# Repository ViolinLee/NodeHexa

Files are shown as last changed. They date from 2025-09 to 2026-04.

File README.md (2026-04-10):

# 🤖 NodeHexa - 六足机器人（支持四足构型）

[English README](README_EN.md)

<div align="center">

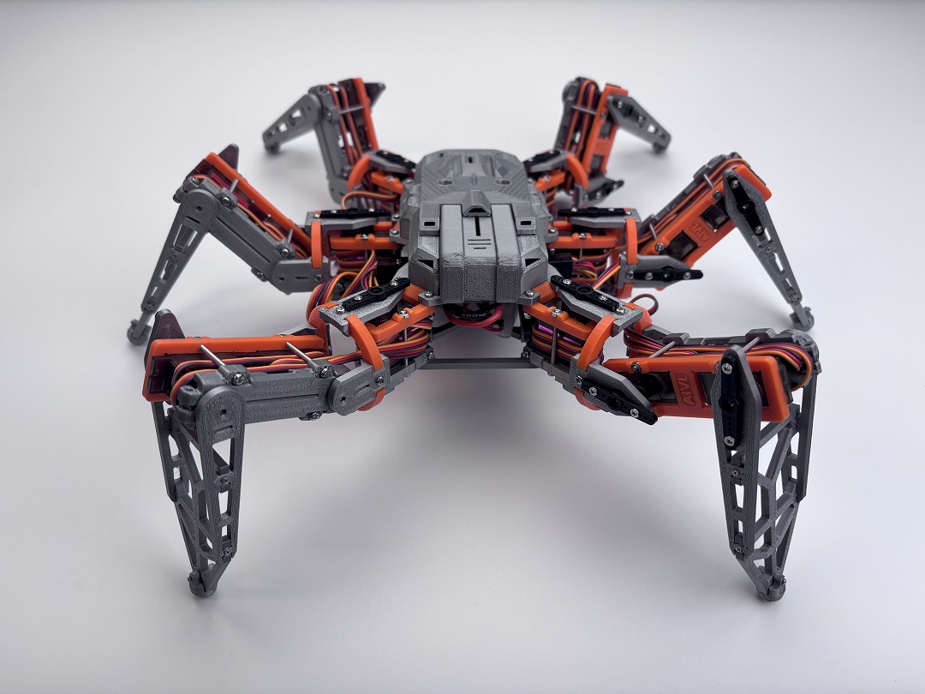
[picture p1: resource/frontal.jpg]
NodeHexa Logo


**一个基于 ESP32 的六足机器人项目，同时额外支持四足构型固件；支持 Web 控制、校准、表演动作与动作序列**






</div>

## 📖 项目简介

NodeHexa 是一个开源的六足机器人项目，基于 ESP32 微控制器开发。项目集成了运动学算法、Web 界面控制、实时校准与动作序列（运动规划）能力，面向机器人爱好者与研究用途。

## 🧩 支持的构型

当前代码仓库同时提供 **四足构型固件** 支持，便于共用一套 Web UI、校准与运动控制框架。

| 构型 | 定位 | 支持范围 | 文档/图片现状 |
| --- | --- | --- | --- |
| **六足（Hexapod / NodeHexa）** | 主线 | 结构/硬件/固件/界面/教程 | 本 README 的示意图主要为六足；软硬件设计完全开源 |
| **四足（Quadruped / NodeQuadMini）** | 额外支持 | 结构/原理图/固件/界面 | 本 README 已包含四足展示图；硬件侧提供原理图参考（PCB 未开源）；待更新教程 |

> 结构件与紧固件差异：见 `mechanism/README.md`（已按六足/四足分别列出）。

## ✨ 核心特性

### 🧩 双构型支持（六足为主，四足为额外支持）
- **统一抽象接口** - 六足/四足共用控制与 Web 框架
- **构型差异隔离** - 六足与四足分别实现，互不影响主线功能演进

### 🎮 多种控制方式
- **Web界面控制** - 通过浏览器实时控制机器人运动
- **串口通信** - 支持UART2串口指令控制（调试和外接上位机用）
- **WebSocket通信** - 低延迟的实时数据传输
- **语音拓展（可选）** - 支持接入“小智 AI 拓展板”，实现语音交互控制

### 🚀 丰富的运动模式
- **基础移动**: 前进、后退、左转、右转
- **侧向移动**: 左移、右移
- **姿态控制**: X/Y/Z轴旋转、扭转动作
- **特殊动作**: 攀爬、快速前进
- **表演模式**: 自由律动、节拍摇摆、登场秀
- **动作按钮模式切换**: 支持“持续”与“单次（单周期）”两种触发方式，普通动作与表演动作都会随设置切换执行方式
- **单腿演示模式（仅六足）**: 可单独选择一条腿进行前后/左右/抬升演示
- **四足多步态切换**: 支持 Trot / Walk / Gallop / Creep 步态模式切换
- **动作序列（运动规划）**: 将多段动作按“周期/步数/距离/角度”等约束编排成序列，一键执行（见 `/planner`）

### 🔧 精确校准系统
- **实时校准** - 通过Web界面进行舵机角度可视化校准
- **参数保存** - 校准数据自动保存到Flash存储

### 🔋 安全保护功能
- **电量显示** - 主控制页与运动规划页实时显示电压和估算电量百分比
- **电池监测** - 实时监控电池电压
- **低电压保护** - 自动LED警告和系统保护

## 🏗️ 技术架构

### 硬件平台
- **主控**: ESP32 (NodeMCU-32S)
- **舵机驱动**: PCA9685 PWM驱动板
- **通信**: WiFi + UART2串口
- **存储**: SPIFFS文件系统
- **语音拓展（可选）**: 小智 AI 拓展板

### 软件架构
```
firmware/
├── src/
│   ├── main.cpp          # 主程序入口
│   ├── robot.h            # 统一机器人抽象接口（六足/四足共用）
│   ├── hexapod.h/cpp      # 六足实现
│   ├── quad_robot.h/cpp   # 四足实现
│   ├── leg.h/cpp          # 单腿控制（六足/四足各自实现/复用）
│   ├── movement*.h/cpp    # 运动控制算法与配置表
│   ├── motion_controller* # 动作序列/运动规划执行
│   └── calibration.h/cpp  # 校准系统
├── include/              # 头文件
└── lib/                  # 第三方库
```

## 🎯 运动控制算法

### 运动学计算
- **正运动学**: 根据关节角度计算足端位置
- **逆运动学**: 根据目标位置计算关节角度
- **坐标变换**: 世界坐标系与局部坐标系转换

## 🖼️ 项目展示

### 六足（NodeHexa）结构与硬件设计

<table>
  <tr>
    <td align="center">
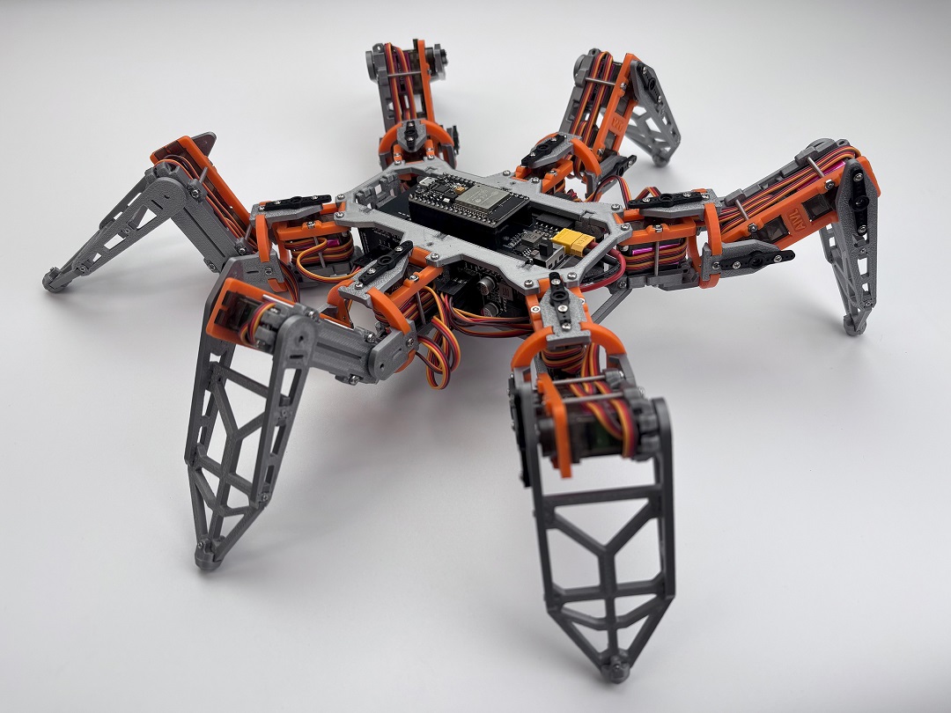
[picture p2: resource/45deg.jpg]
结构设计
      
      <br/>
      <em>六足结构</em>
    </td>
    <td align="center">
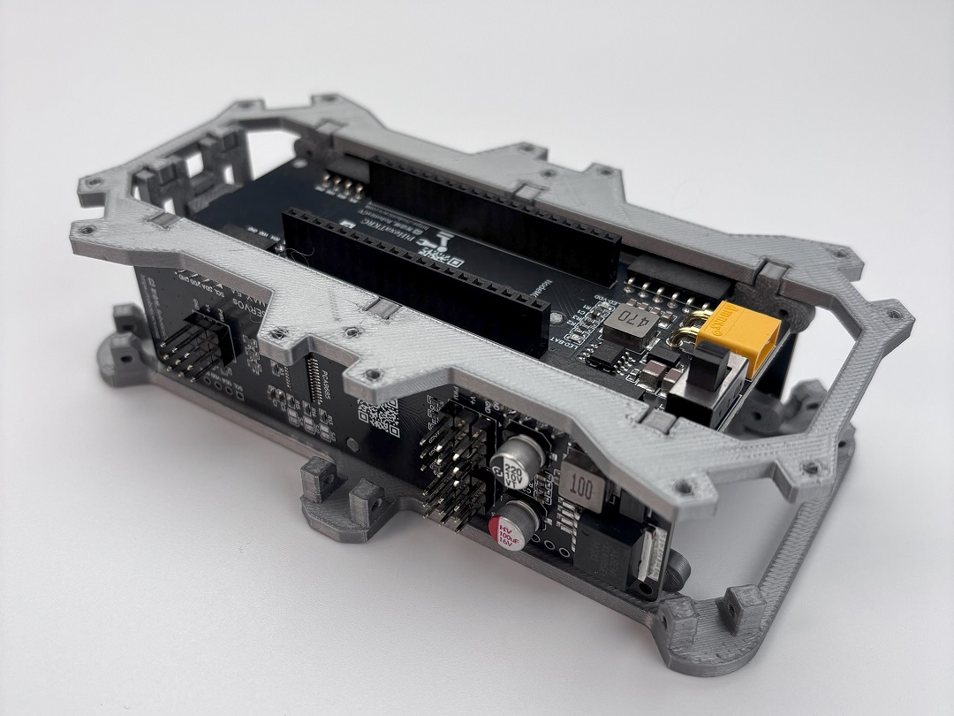
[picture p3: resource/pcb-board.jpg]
PCB电路板
      
      <br/>
      <em>PCB套件</em>
    </td>
    <td align="center">
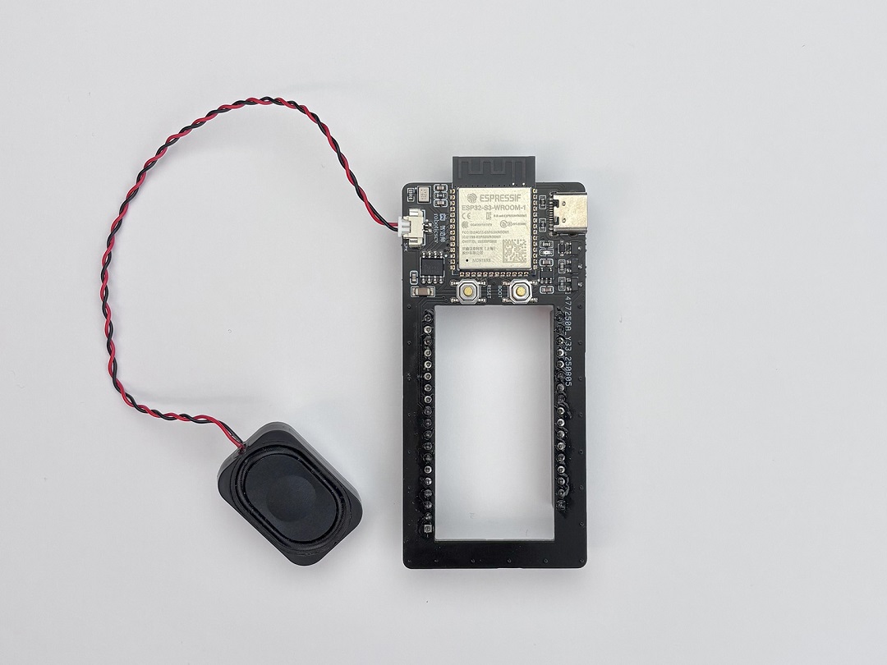
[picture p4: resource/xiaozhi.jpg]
小智拓展板
      
      <br/>
      <em>小智拓展</em>
    </td>
  </tr>
</table>

### 四足（NodeQuadMini）结构与硬件设计

<table>
  <tr>
    <td align="center">
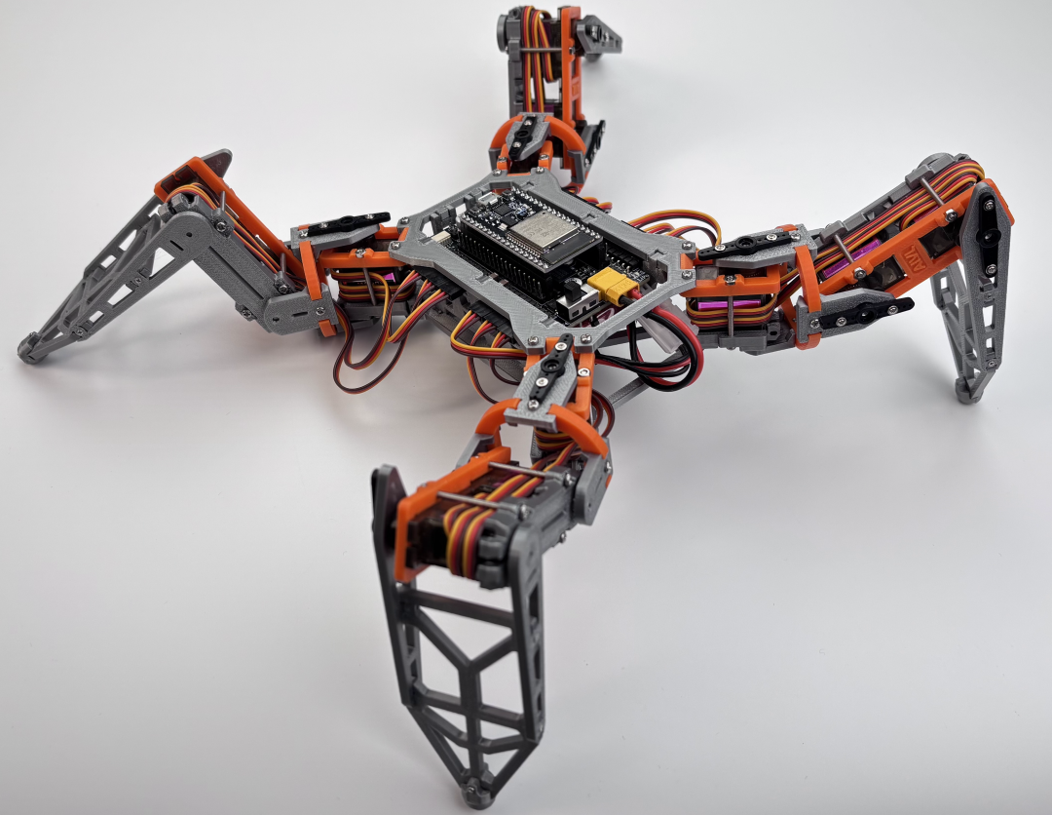
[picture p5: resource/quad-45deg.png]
四足结构
      
      <br/>
      <em>四足结构</em>
    </td>
    <td align="center">
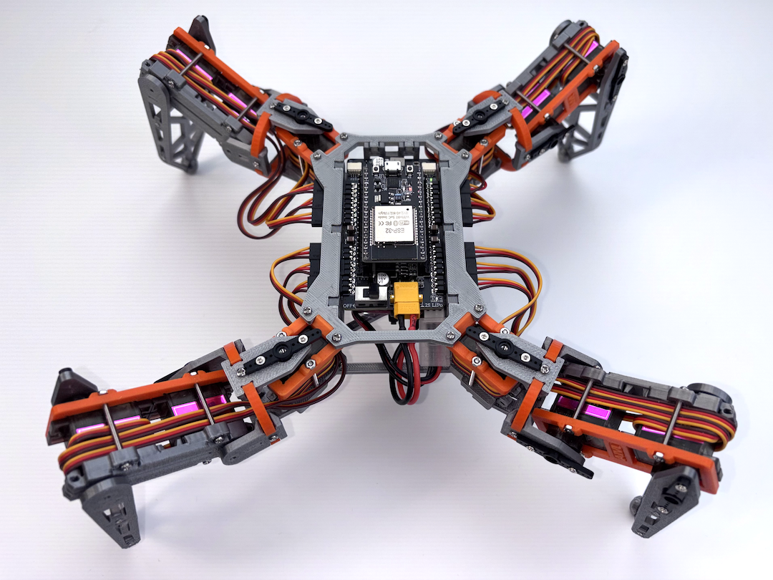
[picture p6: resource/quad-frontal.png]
四足正面
      
      <br/>
      <em>四足正面</em>
    </td>
    <td align="center">
      四足主板
      <br/>
      <em>四足主板</em>
    </td>
  </tr>
</table>

> 说明：四足版本当前开源 **原理图** 供学习与维护参考；PCB 相关文件不开放。
>
> 四足支持多种步态模式切换（Trot / Walk / Gallop / Creep）。

## 🛒 购买链接
- **套件购买**: [NodeHexa 六足机器人套件](https://item.taobao.com/item.htm?ft=t&id=810056770425)、[NodeQuadMini 四足机器人套件](https://item.taobao.com/item.htm?id=1022920495655)
- **电路板购买**：[NodeHexa 六足机器人电路板](https://item.taobao.com/item.htm?id=990145258187)
- **舵机购买（强烈推荐）**: [MG90s 舵机](https://item.taobao.com/item.htm?id=978672014892)
- **语音拓展板购买**: [小智AI拓展板（支持四、六足）](https://item.taobao.com/item.htm?id=989885356650)

> 强烈建议使用我们店铺上架的舵机：市面 MG90s 厂家众多，尺寸与质量差异较大；劣质舵机更容易过热/烧毁，后续成本更高。该链接为我们对多家产品测试对比后筛选的版本。

<div align="center">
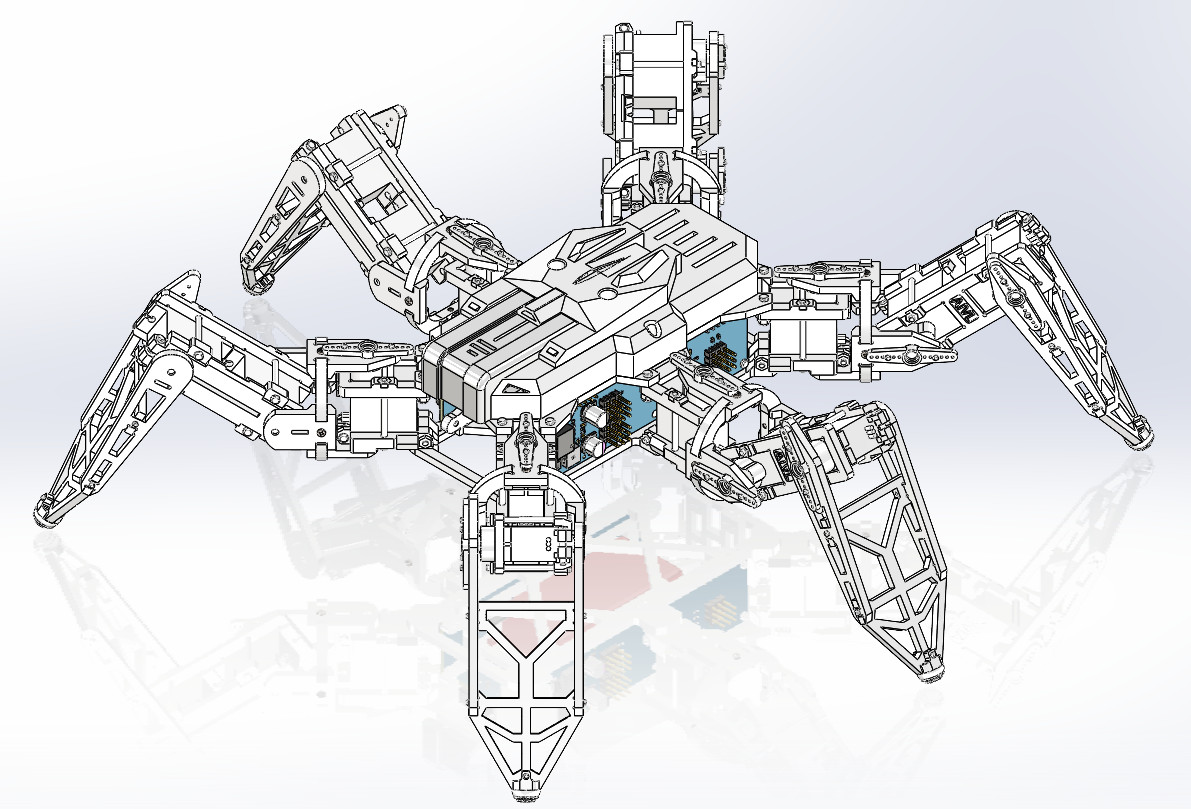
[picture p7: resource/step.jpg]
六足三维模型
  
  <br/>
  <em>六足三维模型预览</em>
</div>

<div align="center">
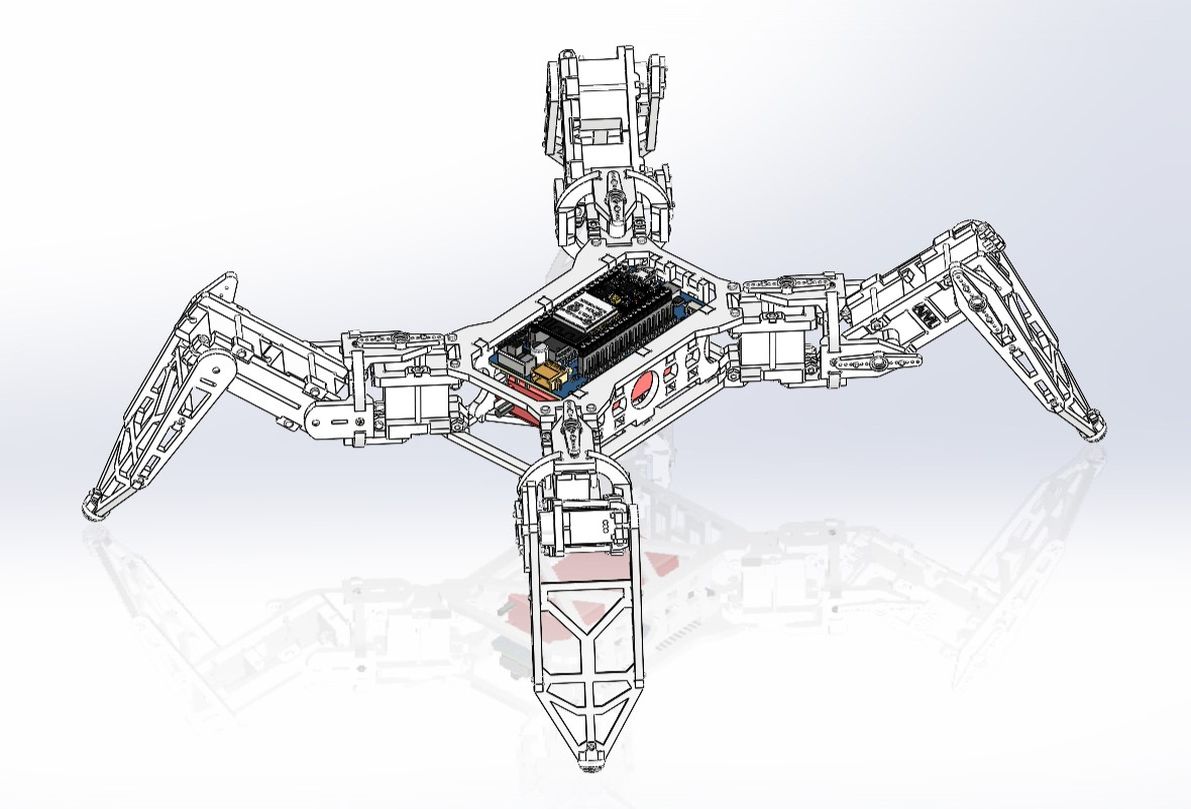
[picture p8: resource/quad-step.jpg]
四足三维模型
  
  <br/>
  <em>四足三维模型预览</em>
</div>

## 📱 复刻教程

<div align="center">

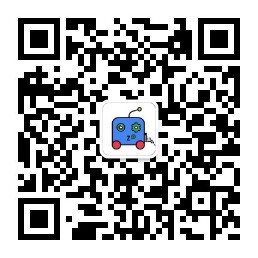
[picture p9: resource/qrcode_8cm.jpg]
公众号二维码
   
*扫描二维码，关注**公众号**发送"**六足**"查看详细复刻**教程**、**交流群**！*

</div>

或点击下方**【NodeHexa教程】**直接查看公众号文章列表：

<details>
<summary><strong>📚 NodeHexa教程</strong></summary>

### 系列教程

1. [六足机器人NodeHexa复刻教程（一）器材准备篇](https://mp.weixin.qq.com/s/QebT1wd3da98jmFbrUHNdA)
2. [六足机器人NodeHexa复刻教程（二）腿部组装篇](https://mp.weixin.qq.com/s/x1spemwsdwfix2QXKvCDqA)
3. [六足机器人NodeHexa复刻教程（三）机身组装篇](https://mp.weixin.qq.com/s/Z3uXM__K4puC-hbytVeSNw)
4. [六足机器人NodeHexa复刻教程（四）编译烧录篇](https://mp.weixin.qq.com/s/InIxQt30JFU6OhD7m3k71Q)
5. [六足机器人NodeHexa复刻教程（五）功能调试篇](https://mp.weixin.qq.com/s/-viItGeh79Q6JDqvxl3oZQ)

### 功能演示

- [【开源】必看！小智 AI 语音交互的六足机器人，带详细复刻教程，做不出来找我"算账"！（B站视频）](https://www.bilibili.com/video/BV19R4gzzEH7)
- [【开源】必看！小智 AI 语音控制六足机器人，开启未来趋势的探索之旅！（微信文章）](https://mp.weixin.qq.com/s/sWiMd9wZ3VoEhoh8ss6X7w)

</details>

## 🚀 快速开始

### 开发环境要求
- 推荐：安装 PlatformIO 插件的 VSCode IDE

### 连接和配置
1. 机器人开机后连接WiFi热点 "NodeHexa" (密码: roboticscv666)
2. 访问 `http://192.168.4.1` 进入控制界面
3. 进行舵机校准 (访问 `/calibration` 页面)
4. （可选）在设置中调整 WiFi AP、低电量保护和动作按钮模式
5. （可选）打开运动规划页面 (访问 `/planner` 页面) 编排动作序列
6. 开始控制机器人运动

## 📱 Web控制界面

### 主控制页面
- **运动控制**: 前进、后退、转向、侧移等
- **姿态控制**: 三轴旋转和扭转动作
- **表演模式**: 自由律动、节拍摇摆、登场秀
- **单腿演示（仅六足）**: 单独选择一条腿并实时控制平移/抬升
- **电量徽章**: 实时显示电压、估算电量和低电量状态
- **设置入口**: 支持修改 WiFi AP、低电量保护、动作按钮模式，并查看固件版本
- **校准功能**: 一键进入校准模式
- **运动规划**: 进入 `/planner` 编排并发送动作序列（单段动作也可直接执行）

### 校准页面
- **实时调整**: 每个舵机的角度微调
- **可视化反馈**: 实时显示调整效果
- **参数保存**: 自动保存校准数据

### 运动规划页面（动作序列）
- **电量显示**: 与主页面同步显示实时电压与电量百分比
- **单段动作**: 执行一段限定周期/步数/距离的动作（姿态类动作仅支持周期）
- **动作序列**: 多段动作串行执行（限制最多 5 段）
- **队列控制**: 支持追加、清空队列与紧急停止

## ❓ 常见问题 (QA)

### 1. 六足舵机驱动板注意事项
**重要提醒**：左右两侧舵机驱动板电路设计完全相同，但在焊接元件时有细小差别。

- 舵机驱动板边缘的1×4P和1×6P排针只焊一侧，左右舵机驱动板焊接位置相反。
- DIY用户需要焊接左侧舵机驱动板的SJ1跳帽（购买套件的用户无需操作，出厂已焊接）。

**作用说明**：焊接跳帽后，左侧舵机驱动板的IIC地址将与右侧不同，避免两块驱动板地址冲突。两块舵机驱动板通过IIC协议与主控通信，地址相同会导致通信异常。

## 🎯 作者

- **B站**: [@智造师_RoboticsCV](https://space.bilibili.com/智造师_RoboticsCV)
- **GitHub**: [@ViolinLee](https://github.com/ViolinLee)
- **微信公众号**: RoboticsCV

## 🤝 贡献指南

欢迎提交Issue和Pull Request来改进项目！

## 🙏 致谢

- 基于 [hexapod-v2-7697](https://github.com/SmallpTsai/hexapod-v2-7697) 项目二次开发
- 参考 [PiHexa18](https://github.com/ViolinLee/PiHexa18) 项目设计
- 语音拓展来自 [xiaozhi-esp32](https://github.com/78/xiaozhi-esp32)
- 感谢所有开源社区的支持

---

<div align="center">

**⭐ 如果这个项目对你有帮助，请给它一个星标！**

**📺 关注B站 [@智造师_RoboticsCV](https://space.bilibili.com/智造师_RoboticsCV) 获取更多机器人项目**

**💬 关注公众号 `RoboticsCV` 获取技术文章和教程**

Made with ❤️ by [ViolinLee](https://github.com/ViolinLee)

---

Copyright © 2024 ViolinLee. Licensed under GPL-3.0.

</div>

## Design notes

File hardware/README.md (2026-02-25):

# NodeHexa 硬件设计

## 项目概述

本项目包含了六足机器人 NodeHexa 的完整硬件设计文件，采用模块化设计理念，提供了灵活可扩展的硬件解决方案。

## 硬件模块说明

### 📦 硬件文件列表

- **PiHexaSub** - 舵机拓展板PCB工程
- **PiHexa-V4** - 六足机器人主板PCB工程  
- **PiHexaHatXiaozhi** - 六足机器人小智拓展板工程  
- **Schematic_NodeQuadMini-V2.pdf** - 四足机器人电路原理图

### 🔧 设计工具

所有PCB设计均使用 **立创EDA标准版** 进行设计，请使用标准版软件导入和编辑工程文件。

## 📋 使用说明

1. 下载对应的PCB工程文件
2. 使用立创EDA标准版打开工程
3. 根据需要修改设计参数
4. 导出Gerber文件进行PCB制造

## 🌐 开源发布

六足机器人硬件全面开源（原理图 + PCB），供爱好者学习；出于商业化考虑，四足机器人只开源原理图。

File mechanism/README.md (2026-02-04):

# 机器人组装紧固件清单

## 组装所需紧固件说明

本项目现已支持**六足 / 四足双构型**。两种构型的机身件（上/下盖、PCB固定等）紧固件基本一致，但**与“腿/关节数量”直接相关**的紧固件数量会随构型变化。

说明：
- 下表中的“**可选连接**”项（如 `M2×12mm` 与对应螺母）仅在你采用该可选结构方案时才需要；若未使用可选结构，可从BOM中剔除。
- 数量为**不含备品**的建议采购数量，建议按实际装配习惯准备少量余量。

### 六足构型（Hexapod）紧固件BOM

| 类别 | 规格 | 数量 | 说明 |
|---|---|---|---|
| **螺丝** | M2×6mm | 34 | 髋关节与大腿连接螺丝(24) \| 主PCB固定螺丝(2) \| 左右两侧子PCB固定螺丝(8) |
| **螺丝** | M2×10mm | 14 | 髋关节与机身顶板连接螺丝(12) \| 机盖固定螺丝(2) |
| **螺丝** | M2×12mm | 18 | 髋关节/大腿可选连接螺丝 |
| **螺丝** | M2×16mm | 6 | 髋关节与机身底板连接螺丝 |
| **螺丝** | M2×28mm | 36 | 髋关节内部连接螺丝(12) \| 大腿内部连接螺丝(24) |
| **螺丝** | M1.2×5mm | 36 | 舵片 |
| **螺丝** | M1.2×6mm | 24 | 小腿内部连接螺丝 |
| **螺丝** | M1.2×8mm | 6 | 足尖连接螺丝 |
| **螺丝** | M3×4mm | 2 | 机盖固定螺丝（大） |
| **自锁螺母** | M2 | 30 | 髋关节与机身顶板连接螺母(12) \| 髋关节/大腿可选连接螺母(18) |
| **普通六角螺母** | M2 | 42 | 髋关节与机身底板连接螺母(6) \| 髋关节内部连接螺母(12) \| 大腿处螺母(24) |
| **轴销** | M4×6mm | 18 | 髋关节轴销(6) \| 大腿根部轴销(6) \| 小腿根部轴销(6) |

### 四足构型（Quadruped）紧固件BOM

> 机盖螺丝为预留，目前机盖还未设计，可不准备。

| 类别 | 规格 | 数量 | 说明 |
|---|---|---|---|
| **螺丝** | M2×6mm | 17 | 髋关节与大腿连接螺丝(16) \| 主PCB固定螺丝(1) |
| **螺丝** | M2×10mm | 10 | 髋关节与机身顶板连接螺丝(8) \| 机盖固定螺丝(2) |
| **螺丝** | M2×12mm | 12 | 髋关节/大腿可选连接螺丝 |
| **螺丝** | M2×16mm | 4 | 髋关节与机身底板连接螺丝 |
| **螺丝** | M2×28mm | 24 | 髋关节内部连接螺丝(8) \| 大腿内部连接螺丝(16) |
| **螺丝** | M1.2×5mm | 24 | 舵片 |
| **螺丝** | M1.2×6mm | 16 | 小腿内部连接螺丝 |
| **螺丝** | M1.2×8mm | 4 | 足尖连接螺丝 |
| **螺丝** | M3×4mm | 2 | 机盖固定螺丝（大） |
| **自锁螺母** | M2 | 20 | 髋关节与机身顶板连接螺母(8) \| 髋关节/大腿可选连接螺母(12) |
| **普通六角螺母** | M2 | 28 | 髋关节与机身底板连接螺母(4) \| 髋关节内部连接螺母(8) \| 大腿处螺母(16) |
| **轴销** | M4×6mm | 12 | 髋关节轴销(4) \| 大腿根部轴销(4) \|小腿根部轴销(4) |

## 组装注意事项

- 请按照规格要求准备相应数量的紧固件
- 自锁螺母用于需要防松动的连接部位
- 轴销用于关节连接，确保运动顺畅

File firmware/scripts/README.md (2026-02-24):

# 脚本使用说明

## release.py - 固件发布脚本

自动构建、打包并发布固件到 GitHub Release。

### 环境要求

- Python 3.6+
- PlatformIO
- Git 仓库
- `GITHUB_TOKEN` 环境变量（可通过 `scripts/.env` 文件配置）
- `python-dotenv` 包

### 使用方法

```bash
# 构建所有环境（六足 + 四足）
python scripts/release.py

# 只构建六足机器人固件
python scripts/release.py -e nodemcu-32s

# 只构建四足机器人固件
python scripts/release.py -e nodequadmini

# 构建多个指定环境
python scripts/release.py -e nodemcu-32s -e nodequadmini
```

### 支持的环境

- `nodemcu-32s` - NodeHexa (六足机器人)
- `nodequadmini` - NodeQuadMini (四足机器人)

### 功能

1. 从 `platformio.ini` 读取各环境的版本号
2. 构建指定环境的固件
3. 为每个环境创建独立的发布包（ZIP）
4. 上传到 GitHub Release

### 配置

在 `platformio.ini` 的每个环境块中设置版本号：
```ini
build_flags = -D FIRMWARE_VERSION="1.0.0"
```

在 `scripts/.env` 中添加 GitHub Token：
```
GITHUB_TOKEN=your_github_token_here
```

### 自定义 Release 描述

#### 方法一：通过环境变量设置更新内容（推荐）

在发布前设置 `RELEASE_CHANGELOG` 环境变量，支持多行文本：

**Windows PowerShell:**
```powershell
$env:RELEASE_CHANGELOG = @"
- 新增功能：添加了新的运动模式
- 修复问题：修复了校准数据保存的 bug
- 性能优化：提升了运动控制的响应速度
"@
python scripts/release.py
```

**Linux/macOS:**
```bash
export RELEASE_CHANGELOG="- 新增功能：添加了新的运动模式
- 修复问题：修复了校准数据保存的 bug
- 性能优化：提升了运动控制的响应速度"
python scripts/release.py
```

**或在 `.env` 文件中配置：**
```
RELEASE_CHANGELOG=- 新增功能：添加了新的运动模式
- 修复问题：修复了校准数据保存的 bug
- 性能优化：提升了运动控制的响应速度
```

#### 方法二：在代码中修改默认内容

1. 打开 `scripts/release.py`
2. 找到 `get_changelog` 方法（约第 340 行）
3. 修改 `default_changelog` 变量的内容

#### 自定义完整 Release 描述

如果需要修改 Release 的完整结构，可以编辑 `create_github_release` 方法中的 `release_body` 变量（约第 360-385 行）。

当前 Release 描述包含：
- **更新内容**：从环境变量或代码中读取（可自定义）
- **构建信息**：构建时间和包含的固件数量（自动生成）
- **固件列表**：所有环境的固件包列表（自动生成）
- **下载说明**：使用说明
- **烧录地址**：固件烧录地址
- **技术支持**：联系方式

---

## setup_platformio_path.ps1 - PlatformIO PATH 设置

将 PlatformIO 添加到当前 PowerShell 会话的 PATH 中。

### 使用方法

在 PowerShell 中运行：
```powershell
.\scripts\setup_platformio_path.ps1
```

### 说明

- 只影响当前 PowerShell 会话
- 如需永久生效，请手动添加到系统环境变量
- 或每次使用前运行此脚本

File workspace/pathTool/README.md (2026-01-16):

## pathTool

用于生成固件离线动作表（头文件），输出到：`firmware/src/generated/`

### 使用方式

- **生成六足动作表**

```bash
python3 workspace/pathTool/src/main.py --robot hexapod
```

- **生成四足动作表**

```bash
python3 workspace/pathTool/src/main.py --robot quad
```

### 说明

- **输出文件**：
  - 六足：`firmware/src/generated/movement_table.h`
  - 四足：`firmware/src/generated/movement_table_quad.h`
- **依赖**：六足生成需要 `numpy`（首次缺失可执行：`python3 -m pip install --user -U numpy`）

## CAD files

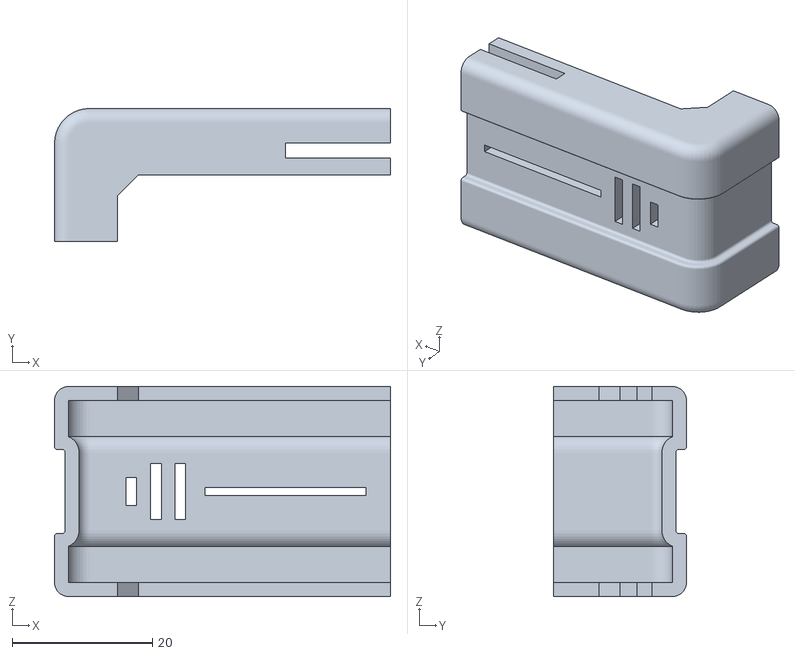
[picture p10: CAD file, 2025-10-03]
mechanism/hat-xiaozhi/TKRC-HATXiaozhi-Front.STL
48.0 x 19.0 x 30.0

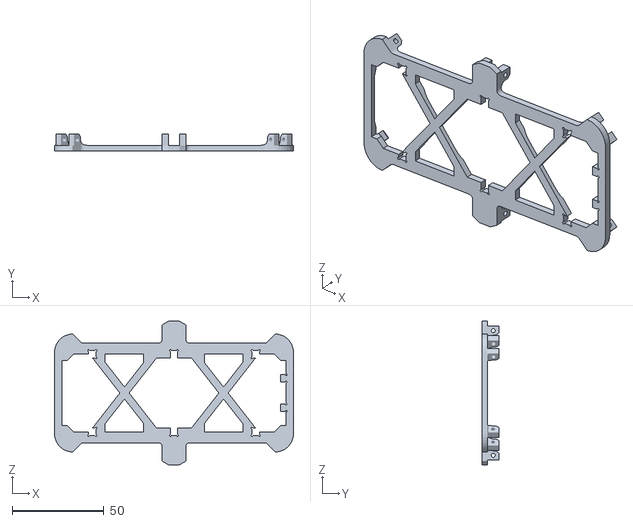
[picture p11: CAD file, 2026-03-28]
mechanism/hexapod/TKRC-BodyButtom-18650-2S.STL
130.3 x 9.00 x 78.3

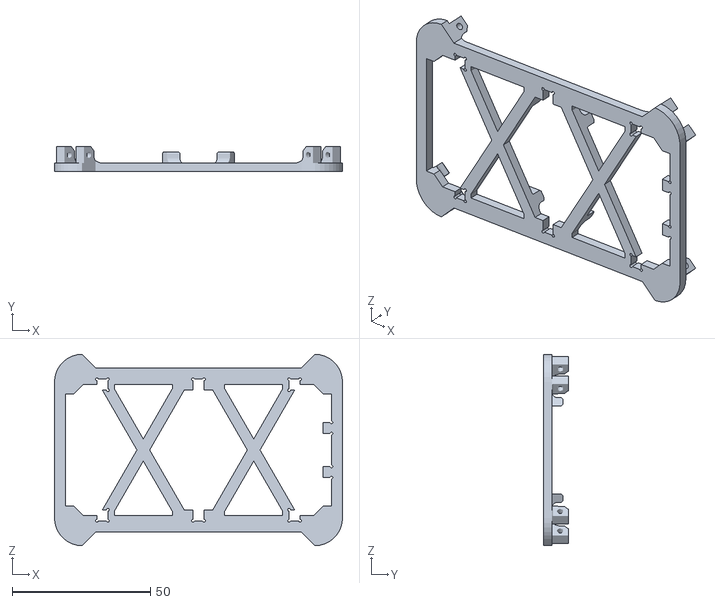
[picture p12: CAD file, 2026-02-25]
mechanism/nodequadmini/NQMN-BodyButtom.STL
104.3 x 9.00 x 69.3

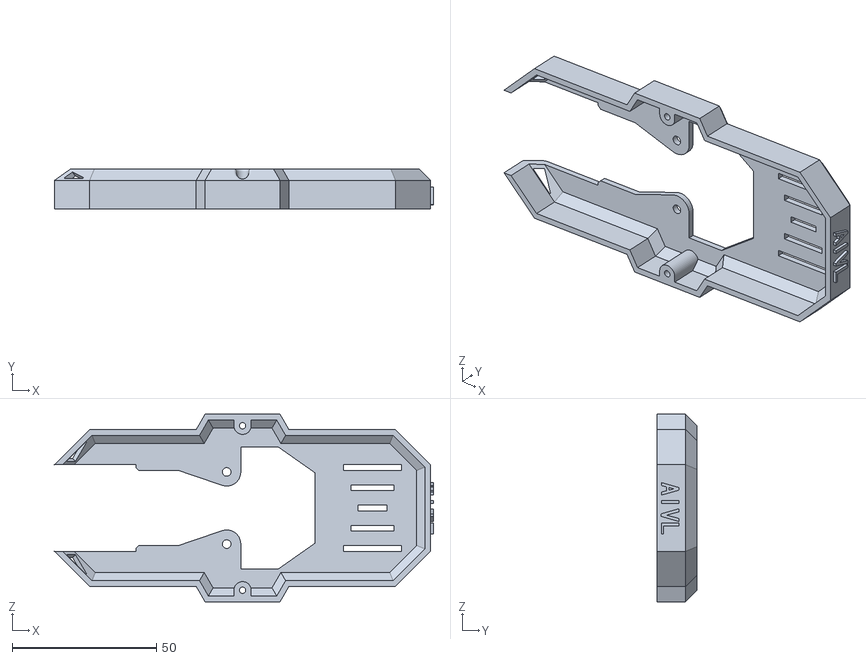
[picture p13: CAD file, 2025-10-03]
mechanism/hat-xiaozhi/TKRC-HatXiaozhi.STL
131.3 x 14.0 x 65.0

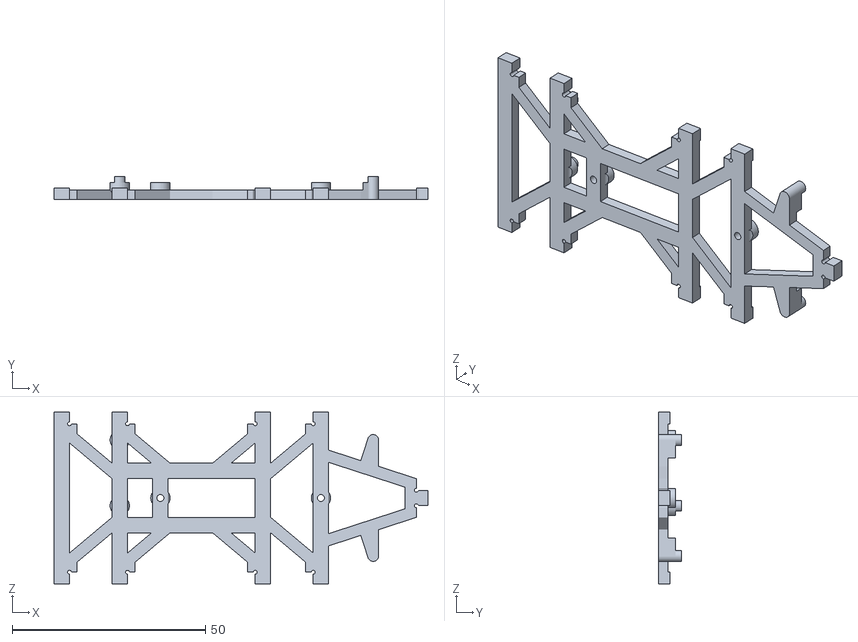
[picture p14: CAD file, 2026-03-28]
mechanism/hexapod/TKRC-BodyCenter-Thin.STL
96.7 x 6.00 x 44.3

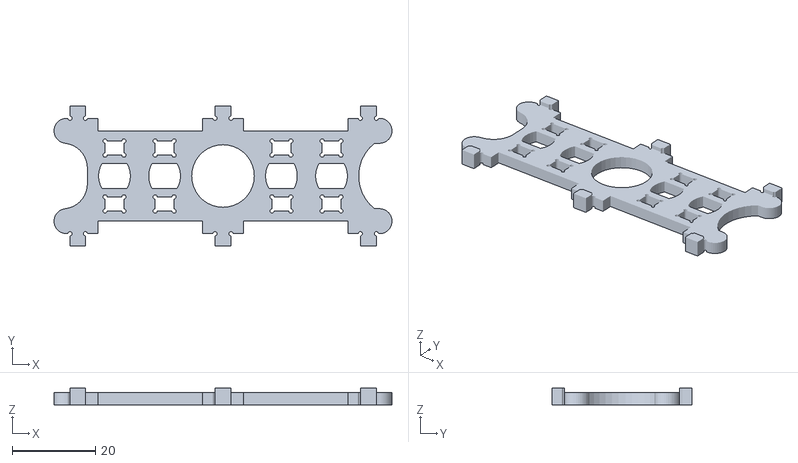
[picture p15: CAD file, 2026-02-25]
mechanism/nodequadmini/MQMN-BodySideWall.STL
81.0 x 33.7 x 4.00

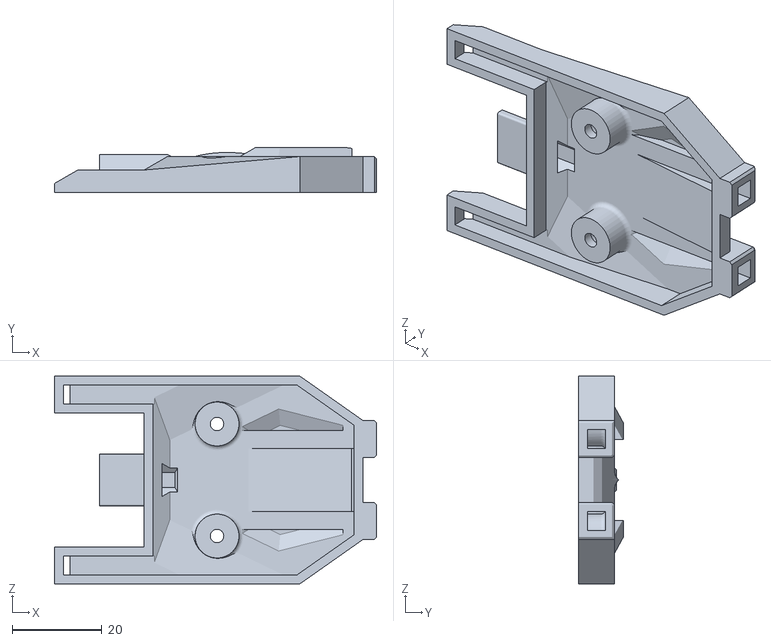
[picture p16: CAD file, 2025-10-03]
mechanism/hat-xiaozhi/TKRC-HATXiaozhi-Top.STL
71.9 x 10.0 x 46.3

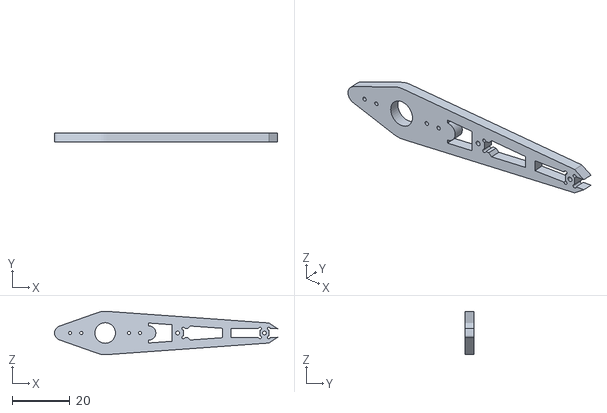
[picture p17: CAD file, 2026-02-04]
mechanism/hexapod/TKRC-FootTop.STL
77.0 x 3.00 x 15.0

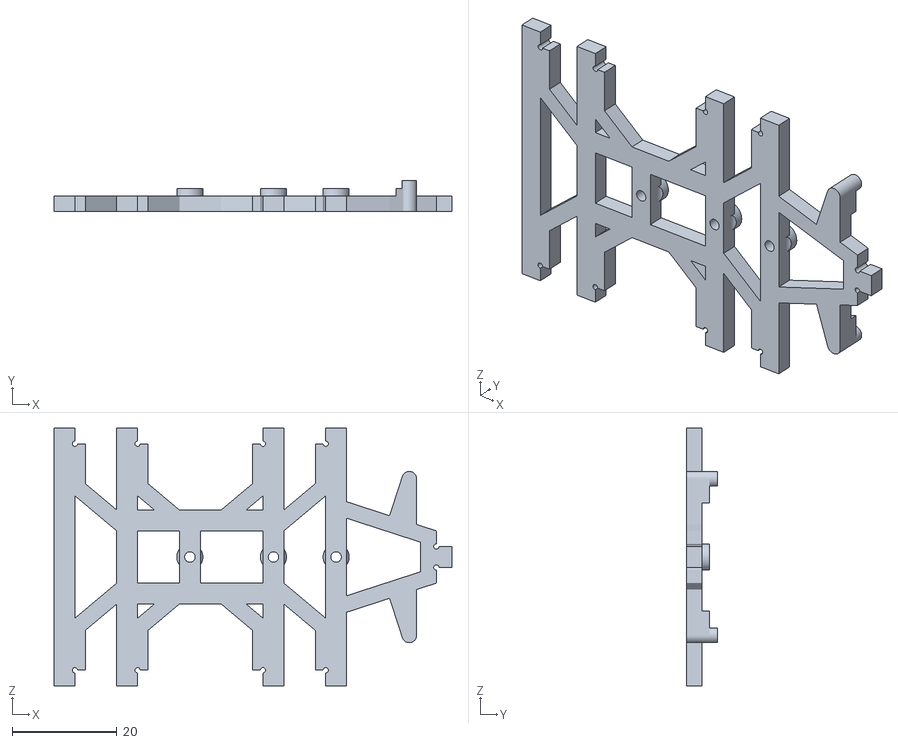
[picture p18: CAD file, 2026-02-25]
mechanism/nodequadmini/NQMN-BodyCenter.STL
76.2 x 6.00 x 49.3

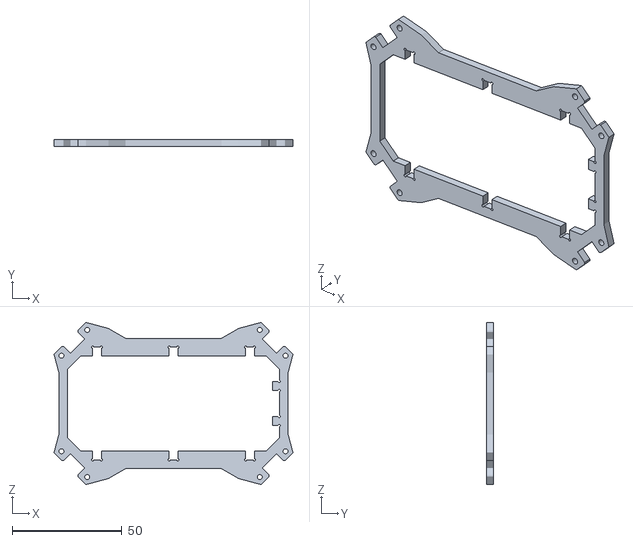
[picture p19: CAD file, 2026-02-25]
mechanism/nodequadmini/NQMN-BodyTop.STL
108.8 x 3.00 x 73.8

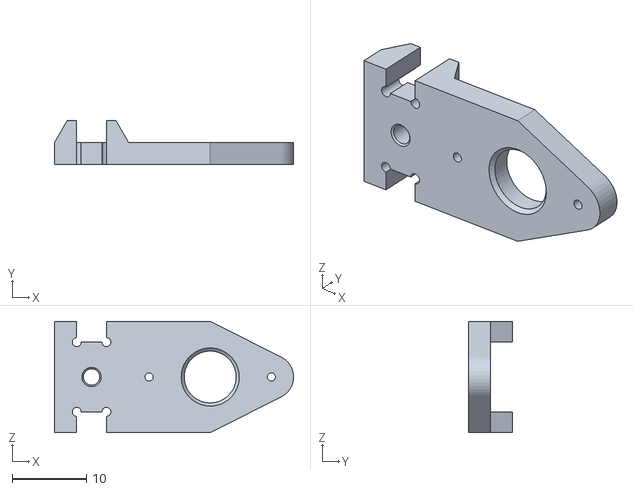
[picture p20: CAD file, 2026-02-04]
mechanism/hexapod/TKRC-JointTop.STL
32.2 x 6.00 x 15.0

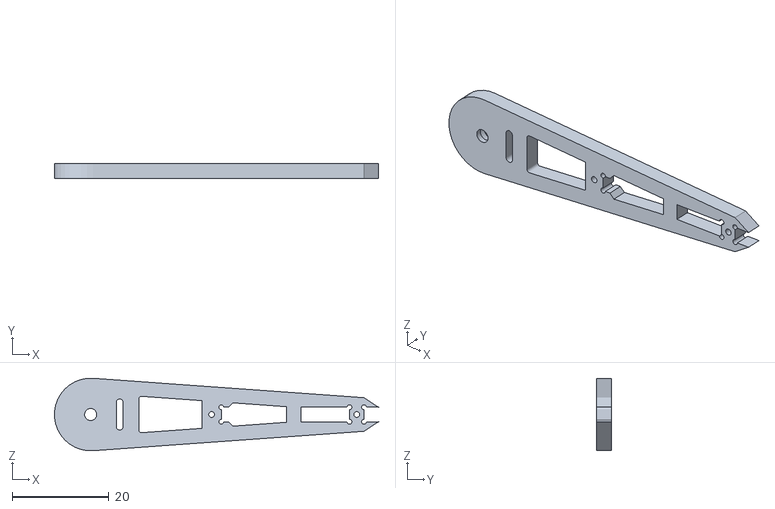
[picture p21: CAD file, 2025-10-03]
mechanism/hexapod/TKRC-FootButtom.STL
67.0 x 3.00 x 15.0

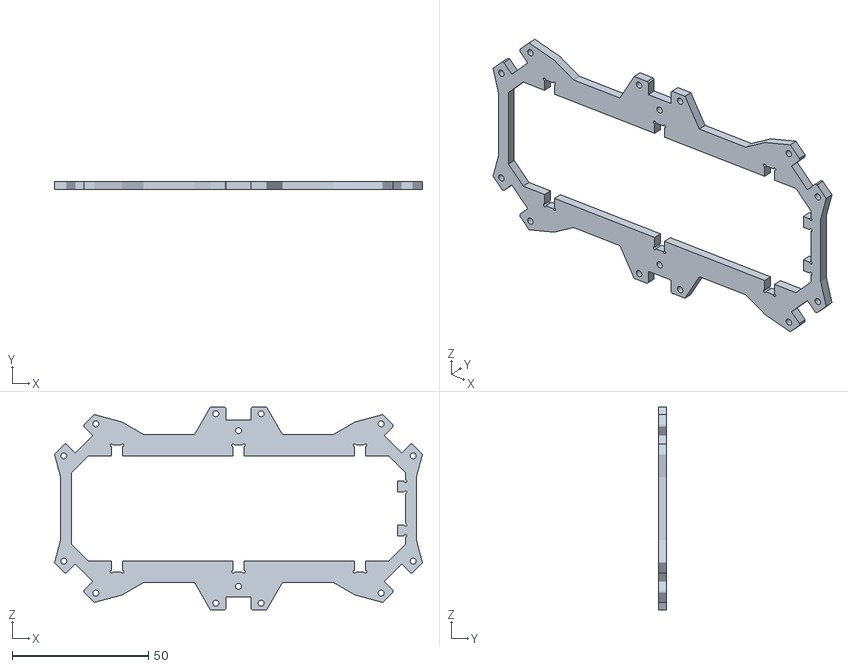
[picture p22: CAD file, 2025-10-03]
mechanism/hexapod/TKRC-BodyTop.STL
134.8 x 3.00 x 74.3

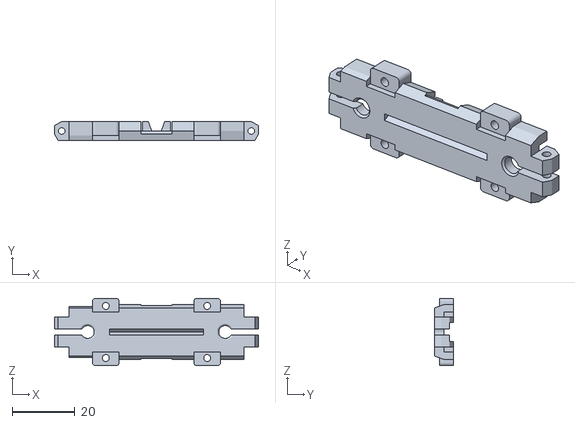
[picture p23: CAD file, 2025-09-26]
mechanism/hexapod/TKRC-LegBottom.STL
65.0 x 6.00 x 21.5

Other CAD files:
mechanism/hexapod/TKRC-BodyButtom.STL
mechanism/hexapod/TKRC-LegTop.STL
mechanism/hexapod/TKRC-ThighBottom.STL
mechanism/hexapod/TKRC-ThighTop.STL
mechanism/hexapod/TKRC-BodyBackWall.STL
mechanism/hexapod/TKRC-BodyCenter.STL
mechanism/hexapod/TKRC-BodySideWall.STL
mechanism/hexapod/TKRC-FootGround.STL
mechanism/hexapod/TKRC-FootTip.STL
mechanism/hexapod/TKRC-JointCross.STL
mechanism/hexapod/TKRC-JointDown.STL

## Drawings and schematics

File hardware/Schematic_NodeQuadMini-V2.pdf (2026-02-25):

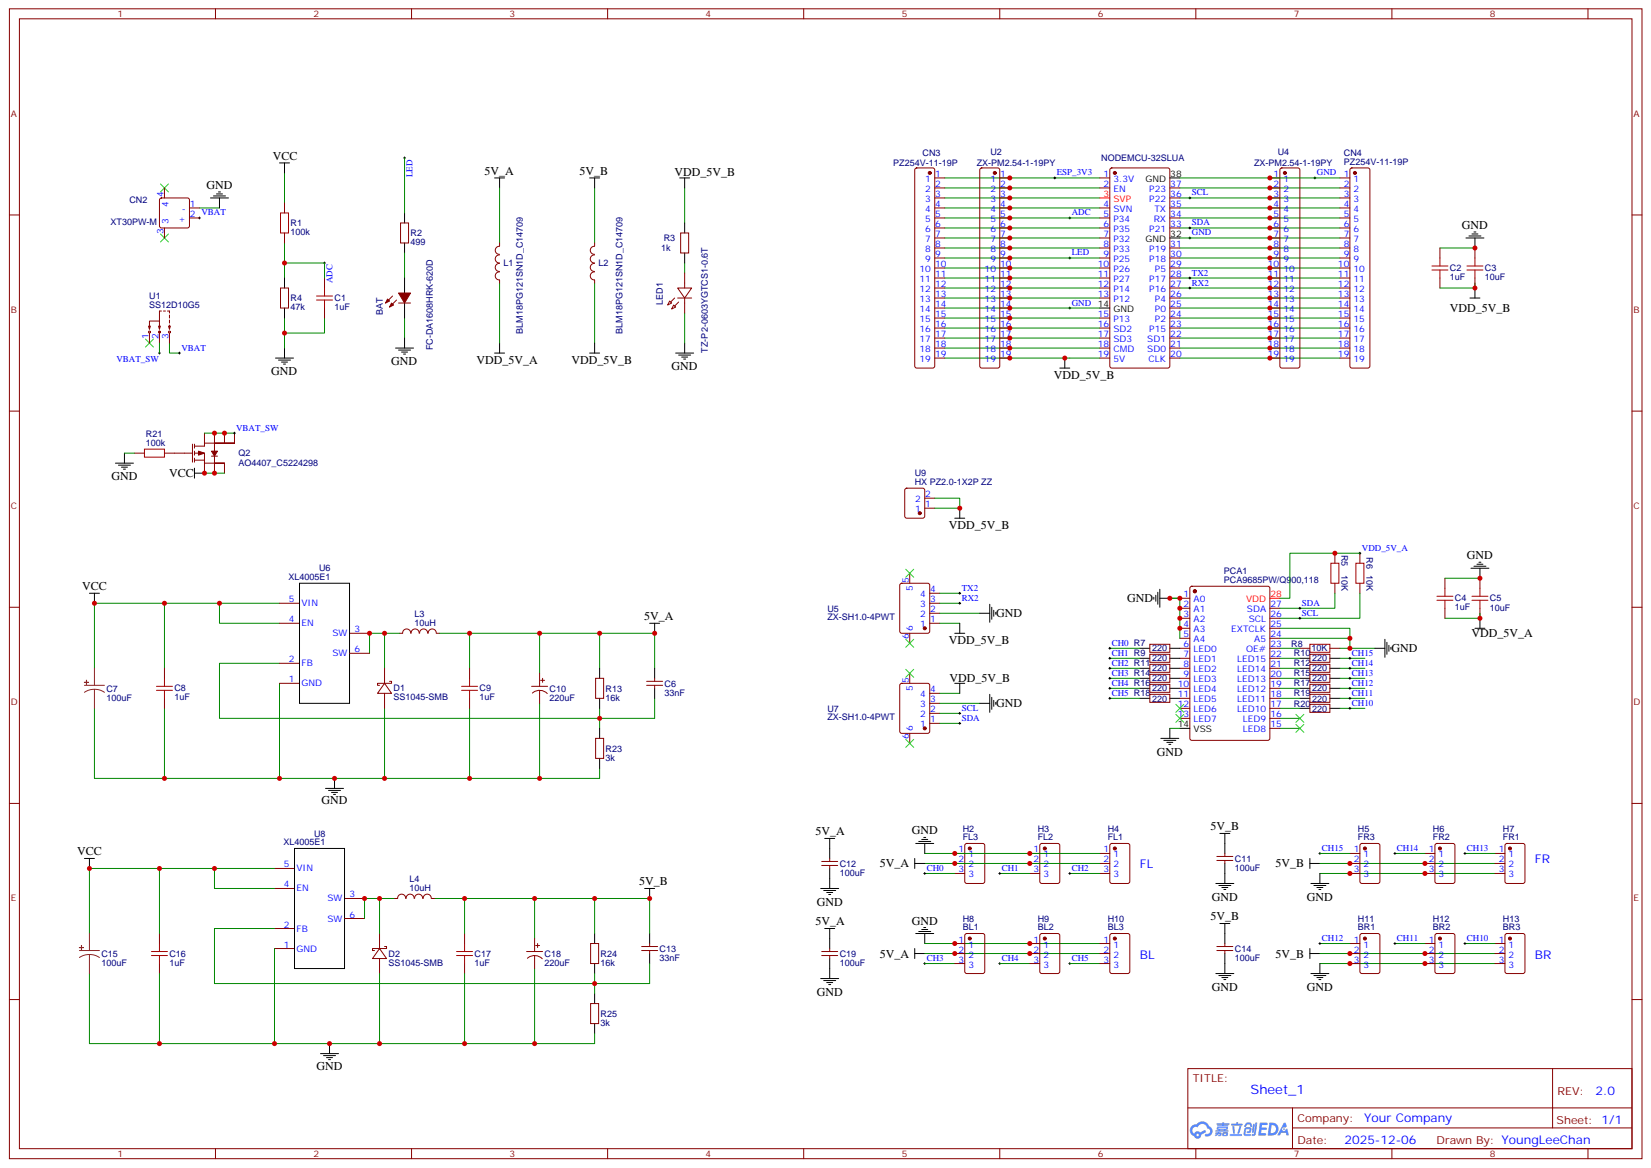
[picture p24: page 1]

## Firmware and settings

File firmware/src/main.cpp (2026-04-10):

/* 六足主程序
 *
 * 移植自项目: [https://github.com/SmallpTsai/hexapod-v2-7697, https://github.com/ViolinLee/PiHexa18]
 * 
 * 腿索引:
 *     leg5   leg0
 *     /        \
 *    /          \
 * leg4          leg1
 *    \          /
 *     \        /
 *    leg3    leg2
 */

/* 架构设计（待删）
_mode和mode的处理在异步的Web服务回调函数中处理
*/

#include <Arduino.h>
#include <Wire.h>
#include <ESPAsyncWebServer.h>
#include <Wifi.h>
#include <ArduinoJson.h>
#include <SPIFFS.h>
#include <HardwareSerial.h>

#include "debug.h"
#include "hexapod.h"
#include "config.h"
#include "calibration.h"
#include "PinDefines.h"
#include "ap_config.h"
#include "device_settings.h"
#include "robot.h"
#include "motion_controller.h"
#include "performance_controller.h"
#include "single_leg_controller.h"

// 宏定义
#define REACT_DELAY hexapod::config::movementInterval
#define CALIBRATESTART "CALIBRATESTART"
#define CALIBRATESAVE "CALIBRATESAVE"
#define CALIBRATESTART_EXISTING "CALIBRATESTART_EXISTING"

// 机型信息（用于 Web UI 自适配）
#ifdef ROBOT_MODEL_NODEQUADMINI
static constexpr const char* kRobotType = "quad";
static constexpr int kRobotLegCount = 4;
static constexpr const char* kCalibrationFilePath = "/calibration_quad.json";
#else
static constexpr const char* kRobotType = "hexa";
static constexpr int kRobotLegCount = 6;
static constexpr const char* kCalibrationFilePath = "/calibration.json";
#endif

// 调试模式控制
// #define DEBUG_ADC_MONITOR  // 注释此行可关闭电池电压ADC调试输出
// #define DEBUG_FRAME_RECEIVE  // 启用帧接收调试输出

// 常量定义

// 串口配置
#define UART2_BAUD_RATE 115200

// 静态变量
static int8_t _mode = 0;  // 六足工作模式：0-运动模式 1-校准模式
static int16_t flag = 0;   // 六足运动模式: 见枚举hexapod:MovementMode
static float test_angle = 0.;

// flag访问保护
SemaphoreHandle_t flagMutex;

// 串口通讯相关变量
static String serialBuffer = "";  // 串口数据接收缓冲区
static const unsigned long SERIAL_TIMEOUT = 1000;  // 串口数据超时时间(ms)
static unsigned long lastSerialDataTime = 0;  // 上次接收串口数据的时间
static bool frameStarted = false;  // 帧接收状态：false-等待起始符$，true-正在接收数据

// 电池监测相关变量
static const float LOW_VOLTAGE_WARNING_THRESHOLD = 7.2f; // UI/警告阈值(V)
static const float LOW_VOLTAGE_LATCH_THRESHOLD_STANDBY = 7.2f; // 待机/校准锁存阈值(V)
static const float LOW_VOLTAGE_LATCH_THRESHOLD_MOVING = 7.0f; // 运动锁存阈值(V)
static const float BATTERY_VOLTAGE_GAIN = 1.0122f; // 采样比例校准
static const uint8_t LOW_BATTERY_LATCH_CONSECUTIVE_SAMPLES = 2; // 连续低压次数阈值
static const unsigned long LOW_BATTERY_SERIAL_REMINDER_INTERVAL_MS = 10000; // 串口提醒重发间隔
// 低电量锁存：一旦置 true，只能通过重启恢复（避免 ADC 电压波动导致忽高忽低）
static bool lowBatteryLatched = false;
static bool lowBatteryHandled = false; // 是否已执行过“强制待机/清队列/通知”动作
static uint16_t latestBatteryVoltageMv = 0;
static constexpr const char* kLowBatteryUiMessage = "电量低，请关闭电源后进行充电！";
static constexpr const char* kLowBatteryProtectCode = "LOW_BATTERY_PROTECT";
static unsigned long lastLowBatterySerialNotifyMs = 0;
SemaphoreHandle_t voltageMutex;

// 实例
AsyncWebServer server(80);
AsyncWebSocket wsRoverCmd("/cmd");

// 函数声明
void handleRoot(AsyncWebServerRequest *request);
void handleCalibrationPage(AsyncWebServerRequest *request);
void handleCalibrationData(AsyncWebServerRequest *request, uint8_t *data, size_t len, size_t index, size_t total);
void handleCalibrationGet(AsyncWebServerRequest *request);
void handleNotFound(AsyncWebServerRequest *request);
void handleMotionPlanner(AsyncWebServerRequest *request);
void sendHtmlFromSpiffs(AsyncWebServerRequest *request, const char *path);
void sendFileFromSpiffs(AsyncWebServerRequest *request, const char *path, const char *contentType);
void onRobotCmdWebSocketEvent(AsyncWebSocket *server, AsyncWebSocketClient *client, AwsEventType type, void *arg, uint8_t *data, size_t len);
void normal_loop();
void setting_loop();
static void log_output(const char* log);
CalibrationData parseCalibrationData(const String& jsonString);
void printWelcomeMessage();

// AP 配置接口声明
void handleApConfigGet(AsyncWebServerRequest *request);
void handleApConfigPostBody(AsyncWebServerRequest *request, uint8_t *data, size_t len, size_t index, size_t total);
void handleApConfigConfirm(AsyncWebServerRequest *request);
void handleApConfigReset(AsyncWebServerRequest *request);

// 最小能力探测接口（仅返回机型与腿数）
void handleCapsGet(AsyncWebServerRequest *request);

// 通用设置接口（用于承载未来更多配置项）
void handleSettingsGet(AsyncWebServerRequest *request);
void handleSettingsPostBody(AsyncWebServerRequest *request, uint8_t *data, size_t len, size_t index, size_t total);
static String* appendRequestBodyChunk(AsyncWebServerRequest *request, const uint8_t *data, size_t len, size_t index, size_t total);
static void clearRequestBodyChunk(AsyncWebServerRequest *request);

void BatteryMonitorTask(void *pvParameters);
void LEDControllerTask(void *pvParameters);

// 串口通讯相关函数声明
void parseSerialMovementCommand(const String& jsonString);
void SerialCommandTask(void *pvParameters);
void sendSerialResponse(const String& message);
void testUART2Connection();
void clearMovementFlag();
static const char* motionButtonModeToString(devsettings::MotionButtonMode mode);
static bool parseMotionButtonModeField(JsonVariantConst value, devsettings::MotionButtonMode& mode);

// 低电量锁存辅助
static bool isLowBatteryLatched();
static void handleLowBatteryLatchedOnce();
static void sendLowBatteryErrorToWebSocket(AsyncWebSocketClient *client);
static void sendLowBatteryErrorToSerial();
static void sendLowBatteryEventToSerial();
static void maybeRepeatLowBatteryEventToSerial();
static uint16_t getLatestBatteryVoltageMv();
static uint8_t estimateBatteryPercent(uint16_t voltageMv);
static bool shouldUseMovingLowBatteryThreshold();

struct AdvancedCommandResult {
  bool handled = false;
  bool success = false;
  bool suppressAck = false;
  uint32_t sequenceId = 0;
  String message;
};

static void handleSequenceComplete(uint32_t sequenceId);
static AdvancedCommandResult handleAdvancedMotionCommand(JsonVariantConst json);
static bool parseMovementModeField(JsonVariantConst value, hexapod::MovementMode& mode);
static bool parsePerformanceKindField(JsonVariantConst value, performance::Kind& kind);
static bool buildActionFromJson(JsonVariantConst obj, motion::Action& action, String& error);
static bool hasActionParameters(JsonVariantConst json);

void setup() {
  // 初始化串口
  Serial.begin(115200);
  Serial.println("Starting...");

  // 初始化UART2用于接收运动指令
  Serial2.begin(UART2_BAUD_RATE, SERIAL_8N1, 16, 17);  // RX=GPIO16, TX=GPIO17 (默认引脚)
  Serial2.setTimeout(100);
  Serial2.flush(); // 清空串口缓冲区
  Serial.printf("UART2 initialized: %d baud (GPIO16-RX, GPIO17-TX)\n", UART2_BAUD_RATE);

  // 初始化电池监测相关硬件
  pinMode(BAT_ADC, INPUT);
  pinMode(BAT_LED, OUTPUT);
  voltageMutex = xSemaphoreCreateMutex();
  flagMutex = xSemaphoreCreateMutex();

  // 初始化I2C
  Wire.setPins(21, 22);

  // 挂载SPIFFS文件系统
  if (!SPIFFS.begin(true)) {
      Serial.println("An Error has occurred while mounting SPIFFS");
      return;
  }

  // 初始化WiFi（动态 AP 配置）
  apconfig::init();
  apconfig::printCurrentAPInfo(Serial);

  // 读取设备设置（NVS）
  devsettings::init();
  Serial.printf("Power: lowBatteryProtectionEnabled=%s\n", devsettings::isLowBatteryProtectionEnabled() ? "true" : "false");

  // 初始化Web服务
  server.on("/", HTTP_GET, handleRoot);
  server.on("/planner", HTTP_GET, handleMotionPlanner);
  server.on("/planner.html", HTTP_GET, handleMotionPlanner);
  server.on("/power_ui.js", HTTP_GET, [](AsyncWebServerRequest *request) {
    sendFileFromSpiffs(request, "/power_ui.js", "application/javascript; charset=utf-8");
  });
  server.on("/single_leg_panel.js", HTTP_GET, [](AsyncWebServerRequest *request) {
    sendFileFromSpiffs(request, "/single_leg_panel.js", "application/javascript; charset=utf-8");
  });
  server.on("/calibration", HTTP_GET, handleCalibrationPage);
  server.on("/calibration", HTTP_POST, 
    [](AsyncWebServerRequest *request)
    {
      //Serial.println("1");
    },
    [](AsyncWebServerRequest *request, const String& filename, size_t index, uint8_t *data, size_t len, bool final)
    {
      //Serial.println("2");
    },
    handleCalibrationData);
  server.on("/api/calibration", HTTP_GET, handleCalibrationGet);
  server.onNotFound(handleNotFound);

  // AP 配置接口（先注册更具体的路径，再注册通用路径，避免潜在前缀匹配冲突）
  server.on("/api/ap-config/confirm", HTTP_POST, handleApConfigConfirm);
  server.on("/api/ap-config/reset", HTTP_GET, handleApConfigReset);
  server.on("/api/ap-config", HTTP_GET, handleApConfigGet);
  server.on("/api/ap-config", HTTP_POST,
    [](AsyncWebServerRequest *request) {},
    [](AsyncWebServerRequest *request, const String& filename, size_t index, uint8_t *data, size_t len, bool final) {},
    handleApConfigPostBody);

  // UI 能力探测（用于校准页适配四足/六足）
  server.on("/api/caps", HTTP_GET, handleCapsGet);

  // 通用设置接口（承载 WiFi 之外的设置项）
  server.on("/api/settings", HTTP_GET, handleSettingsGet);
  server.on("/api/settings", HTTP_POST,
    [](AsyncWebServerRequest *request) {},
    [](AsyncWebServerRequest *request, const String& filename, size_t index, uint8_t *data, size_t len, bool final) {},
    handleSettingsPostBody);

  wsRoverCmd.onEvent(onRobotCmdWebSocketEvent);
  server.addHandler(&wsRoverCmd);

  server.begin();
  Serial.println("HTTP server started");

  // 初始化日志记录回调函数&机器人工作模式
  hexapod::initLogOutput(log_output, millis);
  if (hexapod::Robot) {
    hexapod::Robot->init(_mode == 1);
  }
  motion::controller().begin();
  performance::controller().begin();
  singleleg::controller().begin();
  motion::controller().setSequenceCallback(handleSequenceComplete);

  // 创建电池监测任务
  xTaskCreate(
    BatteryMonitorTask,
    "BatteryMonitor",
    4096,
    NULL,
    1,
    NULL
  );

  // 创建LED控制任务
  xTaskCreate(
    LEDControllerTask,
    "LEDController",
    4096,
    NULL,
    1,
    NULL
  );

  // 创建串口指令处理任务
  xTaskCreate(
    SerialCommandTask,
    "SerialCommand",
    4096,
    NULL,
    2,  // 提高优先级到2，确保串口数据及时处理
    NULL
  );

  printWelcomeMessage();

  // 测试UART2连接
  testUART2Connection();

  Serial.print("Started, mode=");
  Serial.println(_mode);
}

void loop() {
  // 低电量锁存后：强制回到运动模式（standby），并屏蔽所有控制
  if (isLowBatteryLatched()) {
    if (_mode != 0) {
      _mode = 0;
    }
    normal_loop();
    return;
  }

  if (_mode == 0) {
    normal_loop();
  }
  else if (_mode == 1) {
    setting_loop();
  }
}

// 函数定义
/* 日志输出
*/
static void log_output(const char* log) {
  Serial.println(log);
}

/* 常规（运动）循环模式
*/
void normal_loop() {
  // if(wsRoverCmd.count() == 0) {
  //   delay(1000 - REACT_DELAY);
  // }

  const bool lowBattery = isLowBatteryLatched();
  if (lowBattery) {
    handleLowBatteryLatchedOnce();
    maybeRepeatLowBatteryEventToSerial();
  }

  auto t0 = millis();

  if (lowBattery) {
    if (hexapod::Robot) {
      hexapod::Robot->processMovement(hexapod::MOVEMENT_STANDBY, REACT_DELAY);
    }
    motion::controller().onLoopTick(hexapod::MOVEMENT_STANDBY, REACT_DELAY);
  } else if (singleleg::controller().isActive()) {
    singleleg::controller().onLoopTick(REACT_DELAY);
  } else {
    auto mode = hexapod::MOVEMENT_STANDBY;
    if (motion::controller().hasActiveAction()) {
      mode = motion::controller().activeMode();
    } else {
      if (xSemaphoreTake(flagMutex, portMAX_DELAY) == pdTRUE) {
        for (auto m = hexapod::MOVEMENT_STANDBY; m < hexapod::MOVEMENT_TOTAL; m++) {
          if (flag & (1<<m)) {
            mode = m;
            break;
          }
        }
        xSemaphoreGive(flagMutex);
      }
    }

    if (hexapod::Robot) {
      hexapod::Robot->processMovement(mode, REACT_DELAY);
    }
    // 对四足：动作切换存在“等待 entry/对齐”的过渡期，此时实际执行 mode 可能不同。
    // 为保证序列单位(cycles)的计时准确，应以“实际执行的 mode”来累计 completedCycles。
    const auto executedMode = hexapod::Robot ? hexapod::Robot->executedMovementMode(mode) : mode;
    motion::controller().onLoopTick(executedMode, REACT_DELAY);
  }

  auto spent = millis() - t0;

  if(spent < REACT_DELAY) {
    // Serial.println(spent);
    delay(REACT_DELAY-spent);
  }
  else {
    Serial.println(spent);
  }
}

/* 配置循环模式
*/
void setting_loop() {
  // LOG_INFO("Calibration Mode...\n");
}

/* HandleRoot
*/
void sendFileFromSpiffs(AsyncWebServerRequest *request, const char *path, const char *contentType) {
  if (SPIFFS.exists(path)) {
    request->send(SPIFFS, path, contentType);
  } else {
    String message = "File not found: ";
    message += path;
    request->send(404, "text/plain", message);
  }
}

void sendHtmlFromSpiffs(AsyncWebServerRequest *request, const char *path) {
  // 显式声明 UTF-8，避免不同浏览器对中文编码推断不一致导致乱码
  sendFileFromSpiffs(request, path, "text/html; charset=utf-8");
}

void handleRoot(AsyncWebServerRequest *request) {
    apconfig::autoConfirmIfPending();
    sendHtmlFromSpiffs(request, "/web_controller.html");
}

/* HandleCalibrationPage
*/
void handleCalibrationPage(AsyncWebServerRequest *request) {
  apconfig::autoConfirmIfPending();
  sendHtmlFromSpiffs(request, "/calibration.html");
}

/* handleCalibrationData
*/
void handleCalibrationData(AsyncWebServerRequest *request, uint8_t *data, size_t len, size_t index, size_t total) {
  String body = String((char*)data).substring(0, len);

  // 低电量锁存后：禁止校准动作（避免电压波动导致舵机异常）
  if (isLowBatteryLatched()) {
    request->send(200, "application/json", String("{\"status\":\"error\",\"message\":\"") + kLowBatteryUiMessage + "\"}");
    return;
  }

  CalibrationData calibrationData = parseCalibrationData(body);
  if (calibrationData.modeChanged) {
    if ((calibrationData.operation == CALIBRATESTART) && (_mode == 0)) {
      _mode = 1;
      LOG_INFO("Enter Calibration Mode.");
      if (hexapod::Robot) {
        hexapod::Robot->clearOffset();
        hexapod::Robot->calibrationTestAllLeg(test_angle);
      }

      request->send(200, "application/json", "{\"status\":\"success\"}");
    } else if ((calibrationData.operation == CALIBRATESTART_EXISTING) && (_mode == 0)) {
      // 进入校准模式，但不清零现有偏移；舵机转到90°+offset
      _mode = 1;
      LOG_INFO("Enter Calibration Mode (use existing offsets).");
      if (hexapod::Robot) {
        hexapod::Robot->calibrationTestAllLeg(test_angle);
      }

      request->send(200, "application/json", "{\"status\":\"success\"}");
    } else if ((calibrationData.operation == CALIBRATESAVE) && (_mode == 1)) {
      if (hexapod::Robot) {
        hexapod::Robot->calibrationSave();
        hexapod::Robot->init(_mode == 1, true);
      }
      _mode = 0;
      LOG_INFO("Leave Calibration Mode.");
      request->send(200, "application/json", "{\"status\":\"success\",\"redirect\":\"/\"}");
    }
  } else {
    if (_mode == 1) {
      if (hexapod::Robot) {
        hexapod::Robot->calibrationSet(calibrationData);
        hexapod::Robot->calibrationTest(calibrationData.legIndex, calibrationData.partIndex, test_angle);
      }
      request->send(200, "application/json", "{\"status\":\"success\"}");
    }
  }
}

/* 查询当前校准状态与偏移 */
void handleCalibrationGet(AsyncWebServerRequest *request) {
  StaticJsonDocument<1024> doc;

  bool exists = SPIFFS.exists(kCalibrationFilePath);
  doc["exists"] = exists;

  JsonArray offsets = doc.createNestedArray("offsets");
  // 按机型导出校准数据（四足=4条腿，六足=6条腿）
  for (int i = 0; i < kRobotLegCount; i++) {
    JsonArray leg = offsets.createNestedArray();
    for (int j = 0; j < 3; j++) {
      int offset = 0;
      if (hexapod::Robot) {
        hexapod::Robot->calibrationGet(i, j, offset);
      }
      leg.add(offset);
    }
  }

  String responseStr;
  serializeJson(doc, responseStr);
  request->send(200, "application/json", responseStr);
}

/* UI 能力探测：返回机型、电源与表演能力 */
void handleCapsGet(AsyncWebServerRequest *request) {
  StaticJsonDocument<512> doc;
  JsonObject robot = doc.createNestedObject("robot");
  robot["type"] = kRobotType;
  robot["legCount"] = kRobotLegCount;
  JsonObject power = doc.createNestedObject("power");
  power["lowBatteryLatched"] = isLowBatteryLatched();
  power["lowBatteryProtectionEnabled"] = devsettings::isLowBatteryProtectionEnabled();
  const uint16_t voltageMv = getLatestBatteryVoltageMv();
  power["voltageMv"] = voltageMv;
  power["percentEstimate"] = estimateBatteryPercent(voltageMv);
  power["lowBatteryThresholdMv"] = (uint16_t)(LOW_VOLTAGE_WARNING_THRESHOLD * 1000.0f + 0.5f);

  JsonObject performanceCaps = doc.createNestedObject("performance");
  performanceCaps["freestyle"] = performance::isSupported(performance::Kind::Freestyle);
  performanceCaps["beatsway"] = performance::isSupported(performance::Kind::BeatSway);
  performanceCaps["showtime"] = performance::isSupported(performance::Kind::Showtime);

  JsonObject manualCaps = doc.createNestedObject("manual");
#ifdef ROBOT_MODEL_NODEQUADMINI
  manualCaps["singleLeg"] = false;
#else
  manualCaps["singleLeg"] = true;
#endif

  String responseStr;
  serializeJson(doc, responseStr);
  request->send(200, "application/json", responseStr);
}

static String* appendRequestBodyChunk(AsyncWebServerRequest *request,
                                      const uint8_t *data,
                                      size_t len,
                                      size_t index,
                                      size_t total) {
  if (!request) {
    return nullptr;
  }

  if (index == 0 || request->_tempObject == nullptr) {
    clearRequestBodyChunk(request);
    auto *body = new String();
    body->reserve(total);
    request->_tempObject = body;
  }

  auto *body = static_cast<String*>(request->_tempObject);
  if (!body) {
    return nullptr;
  }

  for (size_t i = 0; i < len; ++i) {
    *body += static_cast<char>(data[i]);
  }

  if (index + len < total) {
    return nullptr;
  }

  return body;
}

static void clearRequestBodyChunk(AsyncWebServerRequest *request) {
  if (!request || !request->_tempObject) {
    return;
  }

  auto *body = static_cast<String*>(request->_tempObject);
  delete body;
  request->_tempObject = nullptr;
}

/* HandleNotFound
*/
void handleNotFound(AsyncWebServerRequest *request) {
    request->send_P(404, "text/plain", "File Not Found");
}

void handleMotionPlanner(AsyncWebServerRequest *request) {
  sendHtmlFromSpiffs(request, "/motion_planner.html");
}

/* AP 配置接口处理
*/
void handleApConfigGet(AsyncWebServerRequest *request) {
  apconfig::APConfig cfg = apconfig::getConfig();
  
  // 检查是否包含密码参数（仅用于调试）
  bool includePassword = false;
  if (request->hasParam("includePassword")) {
    includePassword = request->getParam("includePassword")->value() == "true";
  }
  
  StaticJsonDocument<256> json;
  json["status"] = "success";
  json["ssid"] = cfg.ssid;
  json["pending"] = cfg.pending;
  
  if (cfg.pending) {
    // 如果处于 pending 状态，返回待确认的配置（即当前配置）
    json["nextSSID"] = cfg.ssid;
    if (includePassword) {
      json["nextPassword"] = cfg.password;
    }
    json["currentSSID"] = cfg.prevSsid;
  } else {
    // 正常状态，返回当前配置
    if (includePassword) {
      json["password"] = cfg.password;
    }
  }
  
  String response;
  serializeJson(json, response);
  request->send(200, "application/json", response);
}

void handleApConfigPostBody(AsyncWebServerRequest *request, uint8_t *data, size_t len, size_t index, size_t total) {
  String *body = appendRequestBodyChunk(request, data, len, index, total);
  if (!body) {
    return;
  }
  
  StaticJsonDocument<256> doc;
  DeserializationError error = deserializeJson(doc, *body);
  clearRequestBodyChunk(request);
  
  if (error) {
    request->send(400, "application/json", "{\"status\":\"error\",\"message\":\"Invalid JSON\"}");
    Serial.printf("AP Config: JSON parse error: %s\n", error.c_str());
    return;
  }
  
  if (!doc.containsKey("ssid")) {
    request->send(400, "application/json", "{\"status\":\"error\",\"message\":\"Missing ssid field\"}");
    return;
  }
  
  String ssid = doc["ssid"].as<String>();
  String password = doc.containsKey("password") ? doc["password"].as<String>() : "";
  
  // 验证 SSID 长度（ESP32 限制）
  if (ssid.length() == 0 || ssid.length() > 31) {
    request->send(400, "application/json", "{\"status\":\"error\",\"message\":\"SSID length must be 1-31 characters\"}");
    return;
  }
  
  // 验证密码长度（WPA2 要求 8-63 字符，空密码表示开放网络）
  if (password.length() > 0 && password.length() < 8) {
    request->send(400, "application/json", "{\"status\":\"error\",\"message\":\"Password must be at least 8 characters or empty for open network\"}");
    return;
  }
  
  // 设置新配置
  bool success = apconfig::setNewConfig(ssid, password);
  
  if (success) {
    StaticJsonDocument<256> response;
    response["status"] = "success";
    response["message"] = "AP configuration updated, device will reboot in 3 seconds";
    response["pending"] = true;
    response["nextSSID"] = ssid;
    response["nextPassword"] = password;
    
    String responseStr;
    serializeJson(response, responseStr);
    request->send(200, "application/json", responseStr);
    
    Serial.printf("AP Config: New configuration set - SSID: %s, will reboot...\n", ssid.c_str());
    
    // 延迟重启，让 HTTP 响应先发送
    apconfig::requestReboot(3000);
  } else {
    request->send(500, "application/json", "{\"status\":\"error\",\"message\":\"Failed to set configuration\"}");
  }
}

void handleApConfigConfirm(AsyncWebServerRequest *request) {
  Serial.println("AP Config: Confirm endpoint hit");
  apconfig::confirm();
  
  StaticJsonDocument<128> response;
  response["status"] = "success";
  response["message"] = "AP configuration confirmed";
  
  String responseStr;
  serializeJson(response, responseStr);
  request->send(200, "application/json", responseStr);
  
  Serial.println("AP Config: Configuration confirmed by user");
}

void handleApConfigReset(AsyncWebServerRequest *request) {
  apconfig::resetToDefault();
  
  StaticJsonDocument<128> response;
  response["status"] = "success";
  response["message"] = "AP configuration reset to default, device will reboot";
  
  String responseStr;
  serializeJson(response, responseStr);
  request->send(200, "application/json", responseStr);
  
  Serial.println("AP Config: Reset to default configuration");

  // 延迟重启，确保HTTP响应发出
  apconfig::requestReboot(3000);
  Serial.println("AP Config: Reboot scheduled in 3000 ms");
}
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

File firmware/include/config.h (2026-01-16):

#pragma once

namespace hexapod { 

    namespace config {
        // all below definition use unit: mm
        const float kLegMountLeftRightX = 34.7;
        const float kLegMountOtherX = 25;
        const float kLegMountOtherY = 58;

        // ---- quadruped mounting (NodeQuadMini) ----
        // 四足没有 left/right 专用安装点，四条腿统一用 (±X, ±Y) 的安装点
        const float kQuadLegMountOtherX = 25.0;
        const float kQuadLegMountOtherY = 45.0;

        // 可通过调小该角度（如 30°）增大 X 展开、减小 Y 展开，从而缩小前后/左右稳定裕量差异。
        const float kQuadStanceAngleDeg = 30.0;
        const float kQuadStanceCos = 0.866; // cos(30°)
        const float kQuadStanceSin = 0.5; // sin(30°)
        
        const float kLegRootToJoint1 = 19.4;
        const float kLegJoint1ToJoint2 = 32;
        const float kLegJoint2ToJoint3 = 43.8;
        const float kLegJoint3ToTip = 90.05;


        // timing setting. unit: ms
        const int movementInterval = 20;
        const int movementSwitchDuration = 150;

        // speed control. range: 0.25 - 1.0 (1.0 is fastest)
        const float defaultSpeed = 0.5;
        const float minSpeed = 0.25;
        const float maxSpeed = 1.0;
    }

    // Speed level enumeration
    enum SpeedLevel {
        SPEED_SLOWEST = 0,   // 0.25x (极慢)
        SPEED_SLOW = 1,      // 0.33x (慢速)
        SPEED_MEDIUM = 2,    // 0.5x (中速, default)
        SPEED_FAST = 3       // 1.0x (快速)
    };

    // Speed level to multiplier mapping
    const float speedLevelMultipliers[] = {0.25, 0.33, 0.5, 1.0};

}

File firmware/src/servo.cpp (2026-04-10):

#include "servo.h"
#include "debug.h"

#include "pwm.h"

namespace hexapod { 

    namespace {
        // freq = 50, 1 tick = 1000000 / (50*4096) ~= 5us
        const static int kFrequency = 50;
        const static int kTickUs = 5;
        const static int kServoMiddle = 1500;
        const static int kServoMax = 2500;
        const static int kServoMin = 500;
        const static int kServoRange = kServoMax-kServoMiddle;

        auto pwmLeft = hal::PCA9685(0x41);  // 左侧拓展板需要焊接跳帽以设置I2C地址
        auto pwmRight = hal::PCA9685(0x40);
        bool pwmInited = false;
 
        void initPWM(void) {
            if (pwmInited)
                return;

            pwmLeft.begin();  
            pwmLeft.setPWMFreq(kFrequency);
            pwmRight.begin();  
            pwmRight.setPWMFreq(kFrequency);
            pwmInited = true;
        }

        int hexapod2pwm(int legIndex, int partIndex) {
            switch(legIndex) {
            case 0:     return 5 + partIndex;
            case 1:     return 2 + partIndex;
            case 2:     return 8 + partIndex;
            case 3:     return 16 + 8 + partIndex;
            case 4:     return 16 + 2 + partIndex;
            case 5:     return 16 + 5 + partIndex;
            default:    return 0;
            }
        }

        int pwm2hexapod(int pwm) {
            if(pwm >= 16+8)
                return 9 + pwm - (16+8);
            if(pwm >= 16+5)
                return 15 + pwm - (16+5);
            if(pwm >= 16+2)
                return 12 + pwm - (16+2);
            if(pwm >= 8)
                return 6 + pwm - (8);
            if(pwm >= 5)
                return 0 + pwm - (5);
            if(pwm >= 2)
                return 3 + pwm - (2);
            return -1;
        }

    }

    void Servo::init(void) {
        initPWM();
    }

    Servo::Servo(int legIndex, int partIndex) {
        pwmIndex_ = hexapod2pwm(legIndex, partIndex);
        inverse_ = partIndex == 1 ? true : false;
        adjust_angle_ = partIndex == 1 ? 15.0 : 0.0;
        range_ = partIndex == 0 ? 45 : 60;
        angle_ = 0;
        offset_ = 0;
    }

    void Servo::setAngle(float angle) {
        initPWM();

        if (angle > range_ + adjust_angle_) {
            LOG_INFO("exceed[%d][%f]", pwm2hexapod(pwmIndex_), angle);
            angle = range_ + adjust_angle_;
        }
        else if(angle < -range_ + adjust_angle_) {
            LOG_INFO("exceed[%d][%f]", pwm2hexapod(pwmIndex_), angle);
            angle = -range_ + adjust_angle_;
        }

        angle_ = angle;

        hal::PCA9685* pwm;
        int idx;
        if (pwmIndex_ < 16) {
            pwm = &pwmRight;
            idx = pwmIndex_;
        }
        else {
            pwm = &pwmLeft;
            idx = pwmIndex_ - 16;
        }
        angle -= adjust_angle_;
        if (inverse_)
            angle = -angle;

        int us = kServoMiddle + (angle + offset_)*(kServoRange/90);
        if (us > kServoMax)
            us = kServoMax;
        else if(us < kServoMin)
            us = kServoMin;

        pwm->setPWM(idx, 0, us/kTickUs);
        LOG_DEBUG("setAngle(%.2f, %d)", angle, us);
    }

    float Servo::getAngle(void) {
        return angle_;
    }

}

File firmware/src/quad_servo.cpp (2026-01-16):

#ifdef ROBOT_MODEL_NODEQUADMINI

#include "quad_servo.h"
#include "debug.h"
#include "pwm.h"

namespace quadruped {

    namespace {
        // freq = 50, 1 tick = 1000000 / (50*4096) ~= 5us
        const static int kFrequency = 50;
        const static int kTickUs = 5;
        const static int kServoMiddle = 1500;
        const static int kServoMax = 2500;
        const static int kServoMin = 500;
        const static int kServoRange = kServoMax - kServoMiddle;

        // 单片 PCA9685，地址固定为 0x40
        static hexapod::hal::PCA9685 pwm(0x40);
        static bool pwmInited = false;

        void initPWM() {
            if (pwmInited)
                return;

            pwm.begin();
            pwm.setPWMFreq(kFrequency);
            pwmInited = true;
        }

        // legIndex: 0=FR, 1=BR, 2=BL, 3=FL
        // partIndex: 0=关节1, 1=关节2, 2=关节3
        int quad2pwm(int legIndex, int partIndex) {
            if (legIndex < 0 || legIndex >= 4 || partIndex < 0 || partIndex >= 3)
                return 0;
            static constexpr int kMap[4][3] = {
                {13, 14, 15}, // FR
                {12, 11, 10}, // BR
                {3, 4, 5},    // BL
                {2, 1, 0},    // FL
            };
            return kMap[legIndex][partIndex];
        }
    }

    void ServoQuad::init(void) {
        initPWM();
    }

    ServoQuad::ServoQuad(int legIndex, int partIndex) {
        pwmIndex_ = quad2pwm(legIndex, partIndex);
        inverse_ = (partIndex == 1);        // 与六足保持一致：第二关节反向
        adjust_angle_ = (partIndex == 1) ? 15.0f : 0.0f;
        range_ = (partIndex == 0) ? 45 : 60;
        angle_ = 0.0f;
        offset_ = 0;
    }

    void ServoQuad::setAngle(float angle) {
        initPWM();

        if (angle > range_ + adjust_angle_) {
            LOG_INFO("Quad servo exceed[%d][%f]", pwmIndex_, angle);
            angle = static_cast<float>(range_ + adjust_angle_);
        }
        else if (angle < -range_ + adjust_angle_) {
            LOG_INFO("Quad servo exceed[%d][%f]", pwmIndex_, angle);
            angle = static_cast<float>(-range_ + adjust_angle_);
        }

        angle_ = angle;

        int idx = pwmIndex_;
        angle -= adjust_angle_;
        if (inverse_)
            angle = -angle;

        int us = kServoMiddle + static_cast<int>((angle + offset_) * (kServoRange / 90.0f));
        if (us > kServoMax)
            us = kServoMax;
        else if (us < kServoMin)
            us = kServoMin;

        pwm.setPWM(idx, 0, us / kTickUs);
        LOG_DEBUG("Quad setAngle(%.2f, %d)", angle, us);
    }

    float ServoQuad::getAngle(void) {
        return angle_;
    }

} // namespace quadruped

#endif // ROBOT_MODEL_NODEQUADMINI

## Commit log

2025-09-26 add mechanism and libs
    [TKRC-BodyBackWall.STL, TKRC-BodyButtom.STL, TKRC-BodyCenter.STL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]
2025-10-03 feat: official-account-qrcode & STL
    [TKRC-BodyTop.STL, TKRC-FootButtom.STL, TKRC-FootTop.STL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]
2025-10-05 feat: PCB design
2025-10-12 chore：readme
2025-10-27 feat: xiaozhi extension board
2025-11-08 refactor: calibration function improvement
2025-12-23 refactor: reorder quadruped leg sequences
2025-12-26 refactor: quad trajectory dir & servo seq
2025-12-27 fix: movement delay bug
    [quad_robot.cpp]
2025-12-28 fix: exeed angle limit bug
    [quad_robot.cpp]
2026-01-06 chore: readme add pcb
2026-01-11 feat: set leg's 3trd joint initial angle to 10 deg
2026-01-18 feat: quad default creep; latch low battery; simplify trot switching
2026-01-30 refactor: hole dims optimization
    [TKRC-BodyButtom.STL, TKRC-FootTop.STL, TKRC-JointTop.STL]
2026-02-04 feat: add quadruped fastener BOM
2026-02-04 feat: add device settings entry
2026-02-04 fix: quad motion planner & gait type echo
    [main.cpp, quad_robot.cpp]
2026-02-25 feat: nodequadmini model
    [MQMN-BodySideWall.STL, NQMN-BodyButtom.STL, NQMN-BodyCenter.STL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]
2026-02-25 add nodequadmini schematic
2026-03-25 feat: battery monitor ui
2026-03-26 feat: Repeat Low Battery Event To Serial
2026-03-28 feat: 18650 2s lipo compatibility
    [TKRC-BodyButtom-18650-2S.STL, TKRC-BodyCenter-Thin.STL]
2026-04-08 feat: motion button mode
2026-04-09 refactor: walk gait servo limit optimization
2026-04-10 feat: single leg controller
2026-09-01 feat: centralize NodeHexa board configuration
2026-09-01 feat: add latched low-battery policies
2026-09-01 feat: release servo PWM on low battery
2026-09-01 feat: add mandatory low-battery buzzer cues
2026-09-01 feat: expose low-battery policy in web UI
2026-09-01 feat: add reliable UART v2 framing
2026-09-01 feat: decouple UART parsing from command dispatch
2026-09-01 feat: track UART peripherals and camera state
2026-09-01 feat: add asynchronous ultrasonic diagnostics
2026-09-01 feat: add camera video control mode
2026-09-01 feat: report power state during UART handshake
2026-09-01 refactor: isolate low-battery state management
2026-09-01 fix: enlarge camera speed touch targets
2026-09-04 fix: migrate stale WiFi driver state
2026-09-07 fix: improve camera control UI lifecycle
2026-09-14 feat: bind camera sessions to robot identity
2026-09-15 fix: restart WiFi after restoring driver settings
2026-10-16 docs: update hexapod and quadruped axle pin spec to M4x7mm
2026-10-30 feat: add performance motions and calibrated control for v3.0.2
    Add attack, greeting and curiosity tables through pathTool, with shorter entrances and resampled playback. Share calibrated kinematics and servo limits across motion and single-leg control. Keep the legacy basic-control mask and omit hexapod performance tables from quad builds.
2026-10-31 feat: expose new performances and single-leg status in web controls
2026-11-04 fix: release camera stream on Safari view exit
2026-11-04 fix: finalize v3.0.2 UART stability and production logging

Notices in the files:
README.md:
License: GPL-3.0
